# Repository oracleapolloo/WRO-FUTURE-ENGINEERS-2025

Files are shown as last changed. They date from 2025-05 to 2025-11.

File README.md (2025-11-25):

# WRO-FUTURE-ENGINEERS-2025 - TEAM APOLLO

<p align="center">
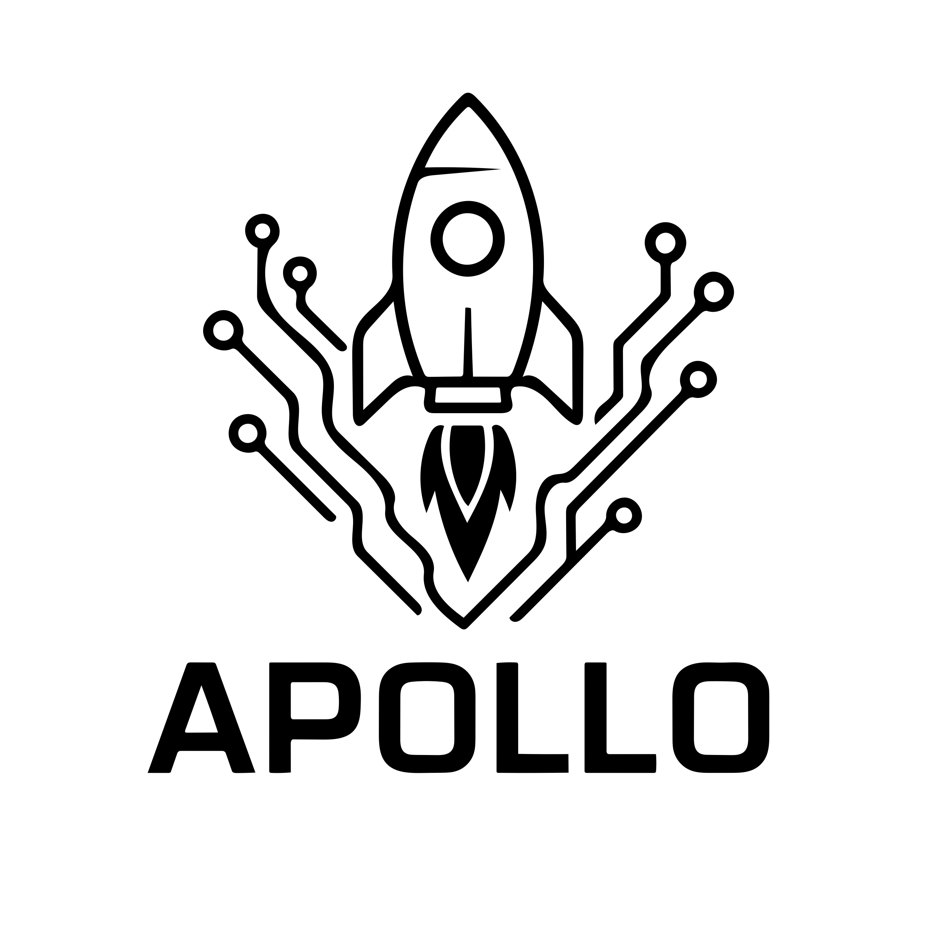
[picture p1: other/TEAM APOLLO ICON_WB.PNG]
  
  
  > An autonomous vehicle designed for the Future Engineers category of the WRO 2025 that uses advanced computer vision and IMU sensors to navigate complex environments and avoid obstacles intelligently.

---
  
##  Content Structure
* `t-photos` – Contains an official team photo and several funny group pics for the vibes 😄.  
* `v-photos` – Includes 6 vehicle images: top, bottom, front, back, left, and right.  
* `video` – Holds `video.md` with a link to the driving demonstration.  
* `schemes` – Contains a PDF file showing the full documentation, wiring, and electromechanical schematics of the robot setup.
* `src` – Full source code for all control components used in the competition.  
* `models` – Contains all STL files required for 3D printing the custom components used in the robot. 
* `other` – Contains all other supporting files, including resources used for the creation of this `README.md` and overall documentation.
* `obstacle challenge & open challenge` – Includes the complete codebase for both challenges.

---

##  Table of Contents

- [Overview](#overview)  
- [Team Introduction & Team Information](#team-introduction--team-information)  
- [Project Description](#project-description)  
- [Hardware Used](#hardware-used)  
- [Software & Libraries](#software--libraries)  
- [Competition Challenges](#competition-challenges)  
- [Spoilers](#spoilers)
  
---

##  Overview
This self-driving vehicle prototype, developed for the WRO Future Engineers 2025 competition, is a fully autonomous system combining real-time decision-making with a compact and modular hardware layout. It features a Limelight 3A for advanced object detection and color-based vision tracking, a REV Robotics 9-Axis IMU for precise orientation sensing and drift correction, and three REV Robotics 2m Distance Sensors for obstacle detection, wall following, and collision prevention. The robot's behavior is governed by a combination of PID control, filtered sensor data, and logic-based navigation, allowing it to maintain center alignment and adapt smoothly to changing track environments. Its structure includes prefabricated parts alongside custom 3D-printed mounts, optimized for precise sensor placement and clean wiring. Power is delivered via an 11.1V lithium-ion battery pack using three 18650 cells. The entire system is programmed using Python on Raspberry Pi 5, with modules communicating through PWM, UART, and I²C protocols to coordinate steering, sensors, and motor control. Altogether, this vehicle presents a robust and competition-ready platform that brings together mechanical design, embedded control systems, and smart autonomous behavior.

---

##  Team Introduction & Team Information
<table>
  <tr>
    <td align="center" width="33%">
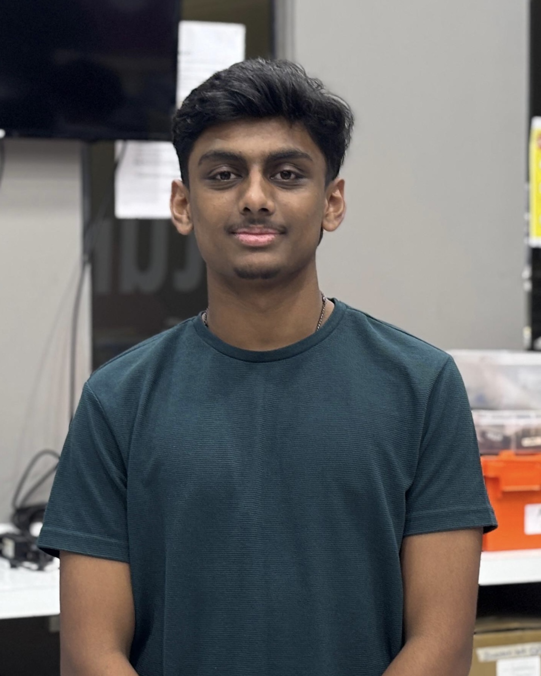
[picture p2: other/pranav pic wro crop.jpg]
      <br>
      <strong>PRANAV NAKKEERAN</strong><br>
      <em>Chief Strategist</em><br>
      <sub>Planning, Analysis, Iteration, Strategy Making</sub>
    </td>
    <td align="center" width="33%">
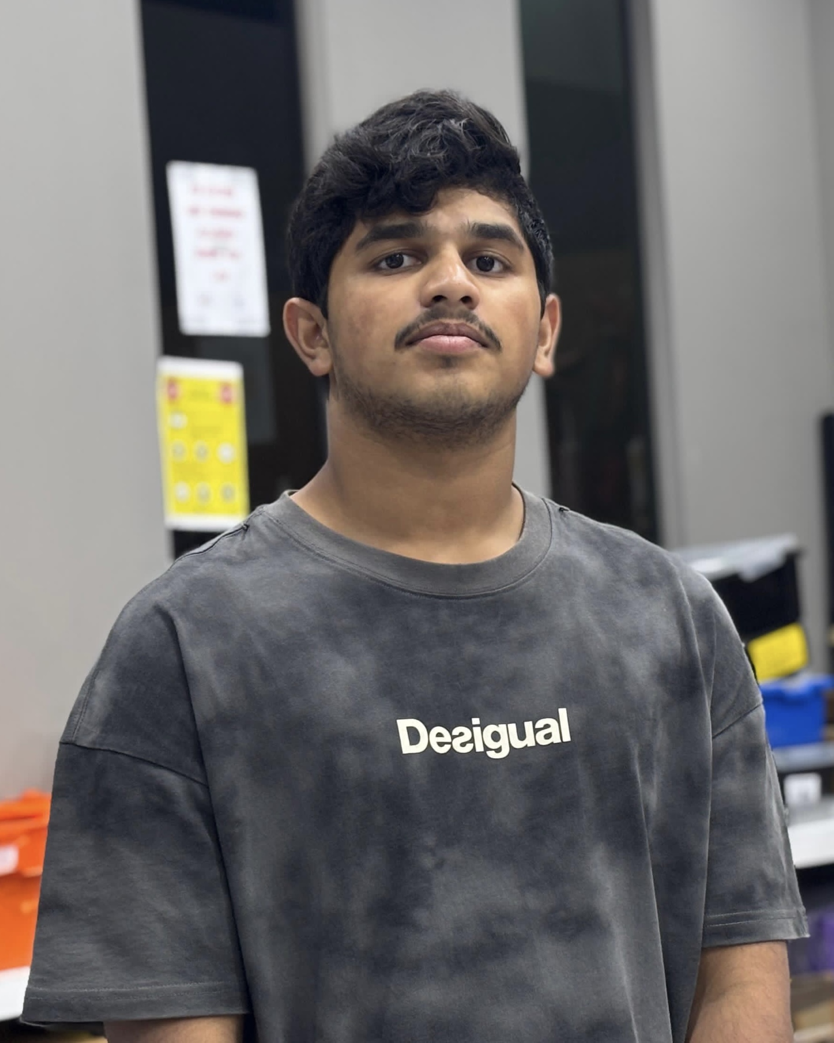
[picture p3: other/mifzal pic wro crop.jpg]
      <br>
      <strong>MOHAMED MIFZAL MAHAROOF</strong><br>
      <em>Hardware Engineer</em><br>
      <sub>Wiring, Circuit Design, Power Management</sub>
    </td>
    <td align="center" width="33%">
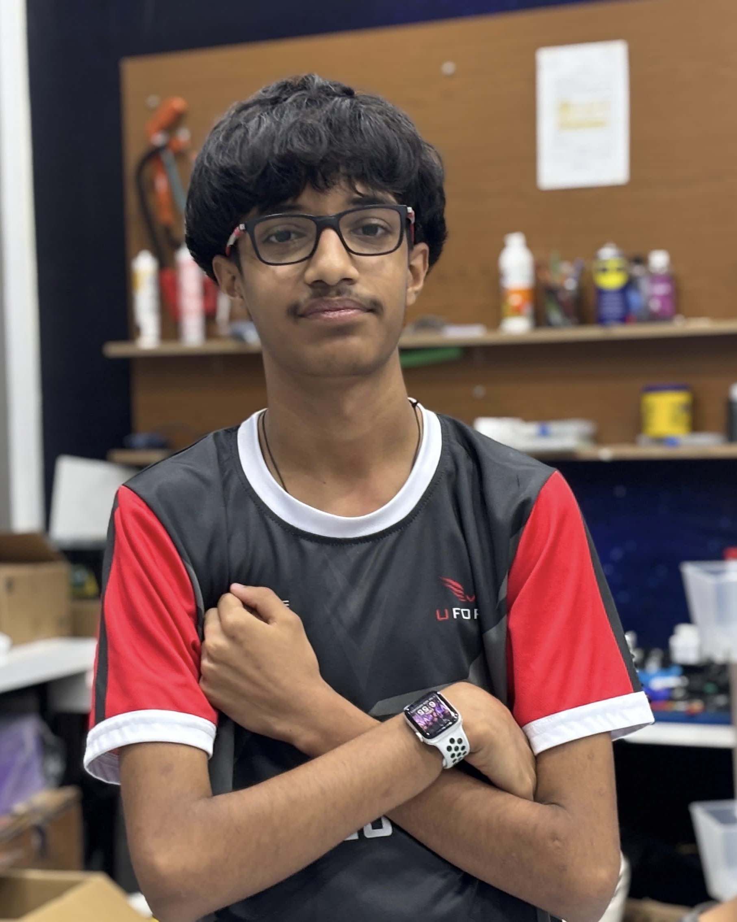
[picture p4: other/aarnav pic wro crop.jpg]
      <br>
      <strong>AARNAV BHARGAVA</strong><br>
      <em>Lead Programmer</em><br>
      <sub>Sensor Integration, Logic, Obstacle Avoidance</sub>
    </td>
  </tr>
</table>

---

##  Project Description

###  Problem Statement
How can a robot dynamically avoid both visible and invisible obstacles in real-time using multi-sensor fusion and advanced vision processing?

###  Goals
- Integrate AI vision with neural network processing for object detection.
- Use 9-axis IMU data to stabilize motion and track orientation with high precision.
- Implement ultrasonic-based distance awareness with improved accuracy.
- Ensure smooth motor control using high-current BTS7960 driver.
- Leverage Raspberry Pi 5's computational power for complex autonomous behaviors.

---

## � Hardware Used

### REV Robotics 2m Distance Sensors (3x)
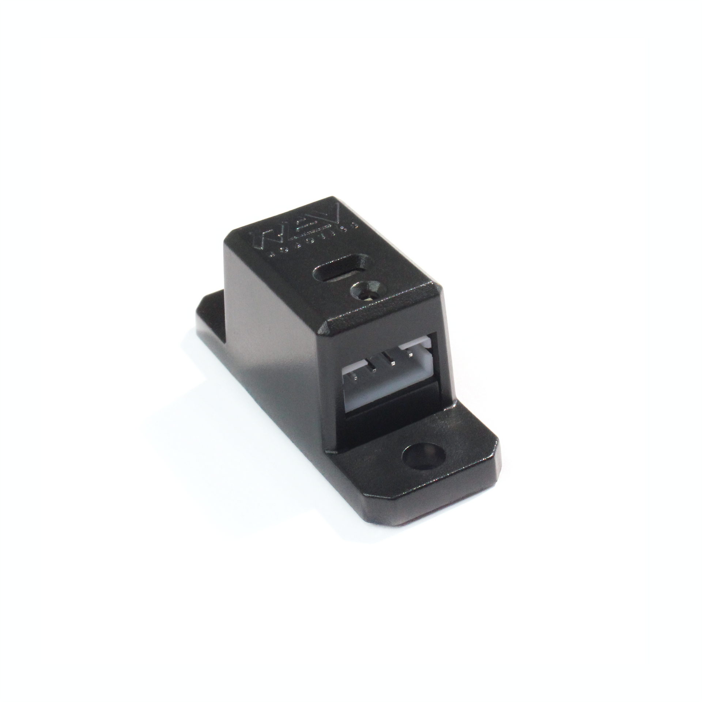
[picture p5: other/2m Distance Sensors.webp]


We selected the REV Robotics 2m Distance Sensor because it is:  
> - **Highly accurate** with ±1cm precision  
> - **Extended range** up to 2 meters for better obstacle detection  
> - **Easy to interface** with Raspberry Pi via I²C  
> - **Industrial-grade reliability** for consistent performance  
> - **Fast sampling rate** for real-time decision making

The REV Robotics 2m Distance Sensor uses Time-of-Flight (ToF) technology to measure distances with exceptional accuracy. Unlike traditional ultrasonic sensors, these ToF sensors emit infrared light pulses and calculate distance based on the time taken for light to reflect back, resulting in more precise and reliable measurements even in challenging lighting conditions.

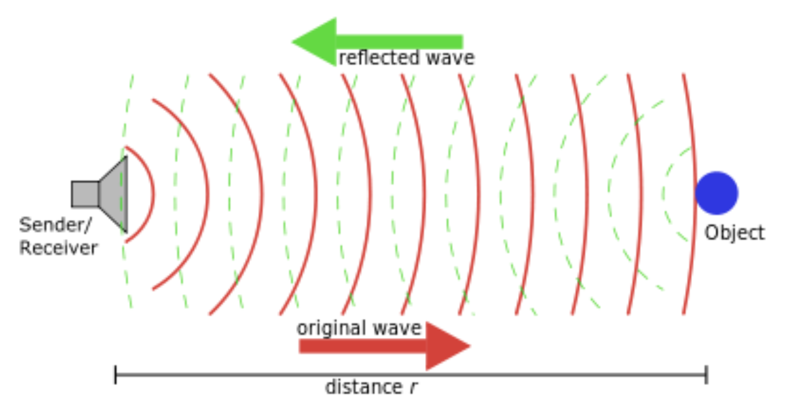
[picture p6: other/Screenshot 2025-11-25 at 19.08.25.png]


In our robot, we used **three REV Robotics Distance Sensors** — positioned at the front, left, and right. The front sensor provides **advanced collision avoidance**, detecting obstacles up to 2 meters away and allowing the robot to plan turns earlier. The side sensors handle **precision wall tracking and edge navigation**, maintaining optimal distance from boundaries while enabling intelligent turning decisions with millimeter-level accuracy.

In software, we utilize the sensors' built-in filtering capabilities and I²C communication protocol for rapid data acquisition. The extended range allows the robot to detect approaching obstacles sooner, giving more time for smooth trajectory adjustments. When the front sensor detects an obstacle, the system analyzes both side distances with high precision to determine the optimal turning direction, enhancing both safety and navigation efficiency.

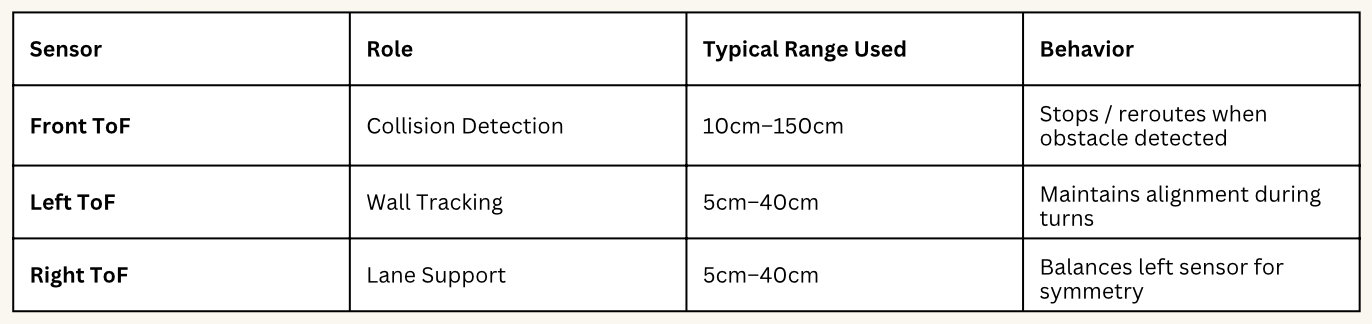
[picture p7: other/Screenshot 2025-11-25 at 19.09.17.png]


<br>

###  Axon MICRO+ Servo Motor
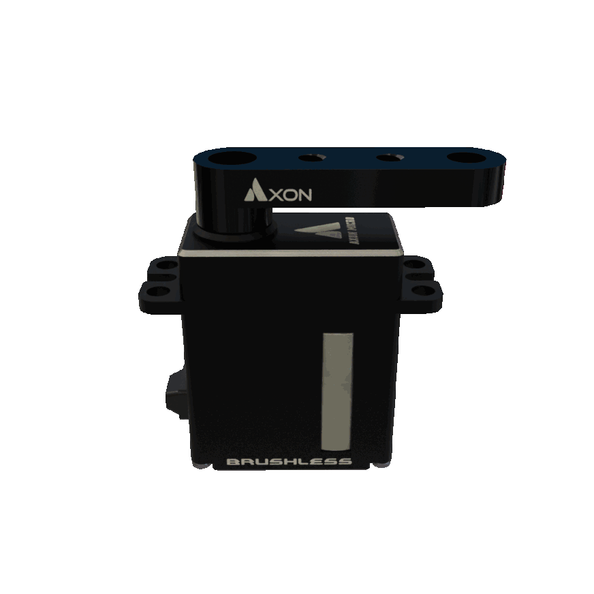
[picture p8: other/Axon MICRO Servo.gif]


Why we chose Axon MICRO+:
>- **270° rotation range** for enhanced steering flexibility
>- **Coreless motor design** for ultra-fast response
>- **Titanium gear construction** for maximum durability
>- **Programmable endpoints** for precise calibration
>- **High torque-to-weight ratio** (4.8kg-cm at 7.4V)
>- **Digital servo protocol** with position feedback

The Axon MICRO+ is a high-performance, programmable digital servo motor featuring coreless motor technology and titanium gears. This advanced servo provides 270° of rotation with exceptional precision and speed, making it ideal for responsive steering control in competitive robotics.

In our robot, we deployed the Axon MICRO+ as the primary steering actuator, enabling real-time directional adjustments with sub-degree accuracy. Its coreless motor eliminates cogging, resulting in silky-smooth motion and instantaneous response to control signals from the Raspberry Pi 5.

The servo is mechanically linked to the front wheels through an optimized Ackermann steering geometry with precision-cut gears. This configuration ensures both wheels turn synchronously at calculated angles, providing accurate steering even during high-speed maneuvers and tight corner navigation.

We selected this servo for its programmable features, allowing us to fine-tune endpoints, speed, and acceleration profiles through software. The titanium gears withstand the stress of repeated rapid movements, essential for completing multiple autonomous laps without mechanical degradation. The digital feedback capability enables closed-loop control, where the Raspberry Pi can verify actual servo position against commanded position, improving overall system reliability.

This motor ensures rapid, consistent, and precise directional control, dramatically improving the robot's agility and responsiveness in both obstacle-rich environments and open track sections while maintaining competitive speed.
<br>

###  AndyMark NeveRest Motor
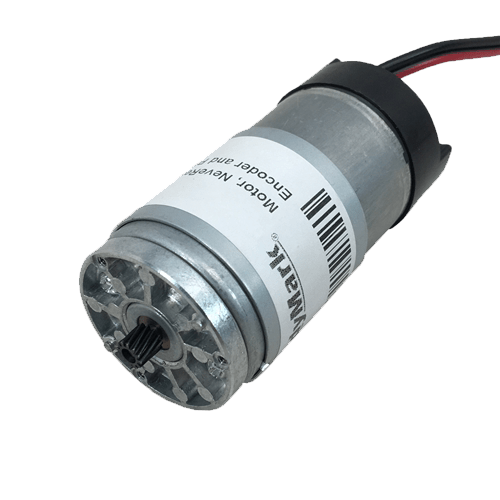
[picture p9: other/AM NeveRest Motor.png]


Why we chose the AndyMark NeveRest:
>- **High torque output** with multiple gear ratios available
>- **Integrated quadrature encoder** for precise position feedback
>- **Robust planetary gearbox** for reliable power transmission
>- **Wide voltage range** (6-12V) for flexible power management
>- **Efficient heat dissipation** for sustained performance
>- **Competition-proven reliability** in FTC/FRC events

The AndyMark NeveRest is a high-performance DC motor featuring a precision planetary gearbox and integrated Hall-effect encoder. This motor delivers exceptional torque while maintaining compact dimensions, making it perfect for driving our robot's differential drivetrain system.

We selected the NeveRest motor with a 20:1 gear ratio, providing an optimal balance between speed and torque for our application. The motor drives the robot's rear wheels through a custom differential assembly, enabling smooth acceleration, controlled speed variation, and reliable linear movement across diverse track surfaces.

The integrated quadrature encoder outputs 1120 counts per revolution, allowing the Raspberry Pi 5 to implement sophisticated closed-loop control algorithms. This encoder feedback enables precise speed regulation, accurate distance measurement, and coordinated motion control essential for executing complex autonomous navigation strategies.

We interface the NeveRest motor with the Raspberry Pi 5 through the BTS7960 high-current motor driver, which handles the motor's power requirements while the Raspberry Pi manages PWM speed control and direction signals. The system continuously monitors encoder feedback to maintain target speeds and adjust for load variations in real-time.

The motor's planetary gearbox provides smooth, reliable power transmission with minimal backlash, crucial for precise movement control during PID-based navigation and tight cornering maneuvers. Its robust construction withstands the repeated start-stop cycles and varying load conditions encountered during autonomous operation.

The combination of high torque, precision feedback, and durability made the NeveRest motor the ideal choice for driving our competition robot through challenging courses while maintaining consistent performance across multiple autonomous runs.
<br>

###  BTS7960 High-Current Motor Driver
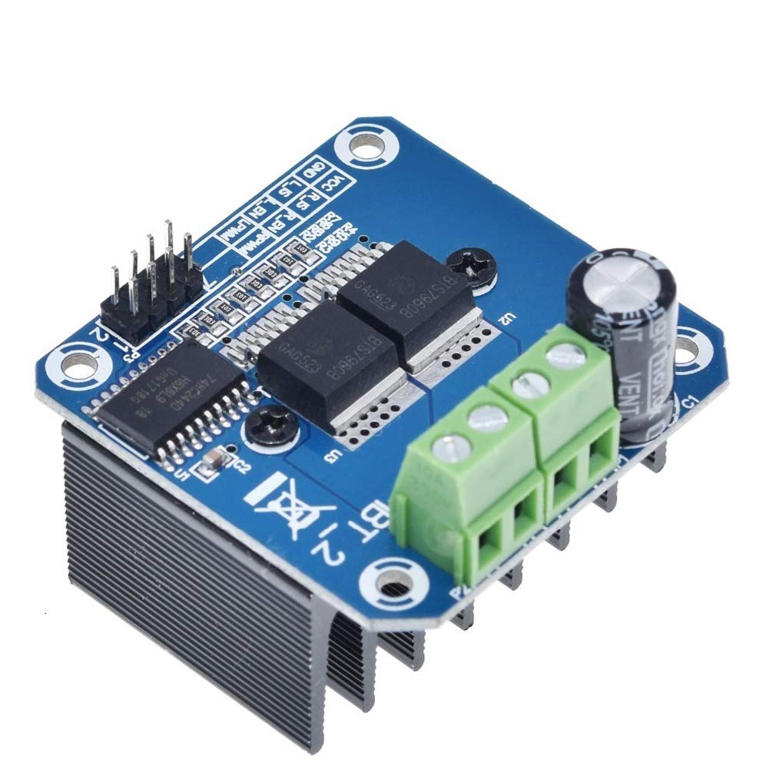
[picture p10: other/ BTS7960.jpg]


Why we chose BTS7960:
>- **High current capacity** up to 43A continuous
>- **Full H-bridge** for bidirectional control
>- **PWM frequency** up to 25kHz for smooth operation
>- **Over-current and thermal protection** built-in
>- **Low voltage drop** for efficient power delivery
>- **Isolated signal inputs** for noise immunity

The BTS7960 is a professional-grade, high-current H-bridge motor driver module capable of handling the demanding power requirements of high-performance DC motors. It features two Infineon BTS7960 chips configured as a full H-bridge, providing robust bidirectional motor control with exceptional current handling capabilities.

In our design, the BTS7960 serves as the primary interface between the Raspberry Pi 5 and the AndyMark NeveRest motor. It receives PWM signals from the Raspberry Pi for speed control and digital logic signals for direction management. This configuration allows us to implement sophisticated motor control algorithms including acceleration profiling, dynamic speed adjustment, and regenerative braking simulation.

The driver's high current capacity (43A continuous, 100A peak) provides substantial headroom for our motor's demands, even during rapid acceleration or high-load situations. This prevents voltage sag and ensures consistent motor performance throughout competition runs. The module's built-in protection features guard against over-current conditions, short circuits, and thermal overload, protecting both the driver and the expensive NeveRest motor.

Unlike lower-capacity drivers, the BTS7960 maintains efficiency at high currents with minimal heat generation thanks to its low RDS(on) and integrated heat sinking. The isolated signal inputs protect the Raspberry Pi from electrical noise generated by motor switching, ensuring stable I²C and encoder signal integrity.

The driver's high PWM frequency capability (up to 25kHz) eliminates audible motor whine and produces smoother torque delivery, particularly beneficial for precision speed control during wall-following and PID correction maneuvers. This results in more stable sensor readings and improved overall system performance.

The BTS7960's combination of high current handling, robust protection features, and clean signal operation made it the essential choice for reliable, high-performance motor control in our competition-grade autonomous vehicle.
<br>

###  Raspberry Pi 5 8GB - Main Controller
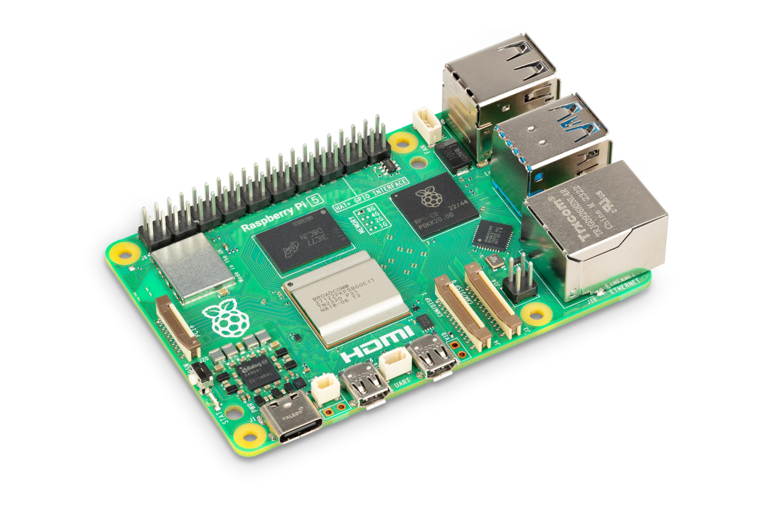
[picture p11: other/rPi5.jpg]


Key reasons we chose the Raspberry Pi 5 8GB:
>- **Quad-core ARM Cortex-A76 CPU** running at 2.4GHz
>- **8GB LPDDR4X RAM** for complex vision processing
>- **Dual 4K display outputs** for development debugging
>- **PCIe 2.0 interface** for high-speed peripherals
>- **Native USB 3.0** for fast data transfer
>- **Real-time capabilities** with improved GPIO performance
>- **Python and C++ support** with extensive libraries
>- **Active community** and professional documentation

The Raspberry Pi 5 represents a significant leap in single-board computer performance, serving as the central processing unit for our autonomous robot. Featuring a quad-core 64-bit ARM Cortex-A76 processor running at 2.4GHz and 8GB of high-speed LPDDR4X memory, it provides the computational power necessary for running complex vision algorithms, sensor fusion, and real-time control systems simultaneously.

In our system architecture, the Raspberry Pi 5 functions as the robot's brain, processing inputs from the Limelight 3A vision system, REV Robotics 9-Axis IMU, and three distance sensors while executing sophisticated navigation algorithms and generating precise control outputs to the BTS7960 motor driver and Axon MICRO+ servo.

We selected the 8GB model specifically to support simultaneous operation of the vision processing pipeline, neural network inference (if required), sensor data filtering, PID controllers, and logging systems without memory constraints. The increased RAM allows us to maintain larger data buffers and implement more sophisticated prediction algorithms for smoother robot behavior.

The Raspberry Pi 5's improved GPIO performance with dedicated RP1 I/O controller enables more reliable PWM generation and faster I²C communication with sensors. This results in higher servo update rates and reduced latency in motor control responses, critical for maintaining stability during high-speed operation.

Programming flexibility is a key advantage - we develop in Python for rapid prototyping and algorithm testing, with the option to optimize critical sections in C++ when needed. The extensive software ecosystem provides libraries for vision processing (OpenCV), numerical computation (NumPy), and hardware interfaces (pigpio, gpiozero), accelerating development and enabling sophisticated features.

The built-in dual-band WiFi enables wireless code deployment, real-time telemetry monitoring, and remote debugging during testing sessions, significantly streamlining our development workflow. The PCIe interface future-proofs our design, allowing for potential addition of AI accelerators or high-speed storage if needed.

Power management is handled efficiently, with the board drawing appropriate current for the computational load while remaining stable under the demanding conditions of autonomous navigation. The improved thermal design with official active cooling accessories ensures sustained performance even during extended competition runs.

The Raspberry Pi 5's combination of processing power, memory capacity, connectivity options, and development ecosystem made it the natural choice for controlling our advanced competition robot, enabling implementation of sophisticated autonomous behaviors that were previously impractical on lower-powered platforms.
<br>

###  REV Robotics 9-Axis IMU – Inertial Measurement Unit
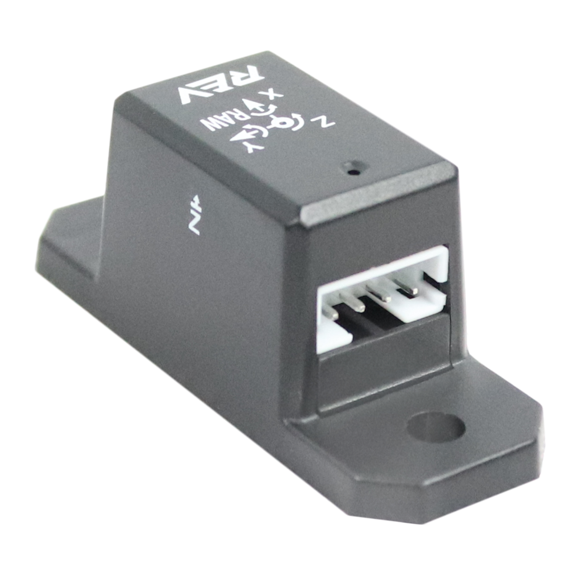
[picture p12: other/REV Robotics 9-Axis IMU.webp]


Why we chose the REV Robotics 9-Axis IMU:
>- **9-axis sensor fusion** (3-axis accelerometer, gyroscope, magnetometer)
>- **BNO055 smart sensor** with onboard processing
>- **Quaternion output** for gimbal-lock-free orientation
>- **Automatic calibration** with persistent storage
>- **I2C interface** compatible with Raspberry Pi
>- **Industrial temperature range** for reliability
>- **Pre-configured** for robotics applications

The REV Robotics 9-Axis IMU features the Bosch BNO055 intelligent sensor, which combines a 3-axis accelerometer, 3-axis gyroscope, and 3-axis magnetometer with an integrated ARM Cortex-M0 processor. This advanced IMU provides real-time orientation data through sophisticated sensor fusion algorithms executed entirely on-chip, offloading computational burden from the main processor.

In our robot, this IMU serves as the cornerstone of our navigation system, providing absolute orientation tracking with exceptional accuracy and stability. The sensor fusion algorithm combines data from all nine axes to output orientation in multiple formats: Euler angles, quaternions, and rotation vectors, giving us flexibility in implementing our control algorithms.

We primarily utilize the IMU's heading (yaw) data for maintaining straight-line tracking and executing precise turns. The quaternion output eliminates gimbal lock issues that plague simpler 6-axis IMUs, ensuring reliable orientation data even during complex maneuvers. The onboard sensor fusion provides filtered, drift-compensated heading values at 100Hz update rates, enabling smooth and responsive PID control.

The BNO055's automatic calibration system is particularly valuable - it continuously monitors sensor performance and adjusts calibration parameters, storing them in non-volatile memory. This means our robot maintains consistent orientation accuracy across power cycles and environmental variations without requiring manual recalibration.

Unlike basic IMUs like the MPU6050, the REV Robotics unit includes a magnetometer for absolute heading reference. This prevents the cumulative drift typical of gyroscope-only solutions, essential for accurate navigation over extended autonomous runs. The accelerometer complements the gyroscope by detecting dynamic motion changes and providing orientation reference during stationary periods.

Integration with the Raspberry Pi 5 is straightforward via I²C protocol, with REV providing well-documented Python libraries specifically designed for FIRST Tech Challenge and educational robotics. These libraries abstract low-level register manipulation while providing access to advanced features like interrupt-driven updates and custom axis remapping.

The IMU's robust construction and industrial-grade components ensure reliable operation despite the vibrations and occasional impacts inherent in competitive robotics. Its compact form factor and mounting hole pattern facilitate secure installation at the robot's center of gravity, minimizing rotational coupling effects that could introduce noise into orientation measurements.

The combination of sophisticated sensor fusion, absolute heading reference, automatic calibration, and reliable performance made the REV Robotics 9-Axis IMU the definitive choice for providing our robot with accurate, stable orientation data essential for precise autonomous navigation and smooth motion control.
<br>

###  Limelight 3A - Advanced Vision Sensor
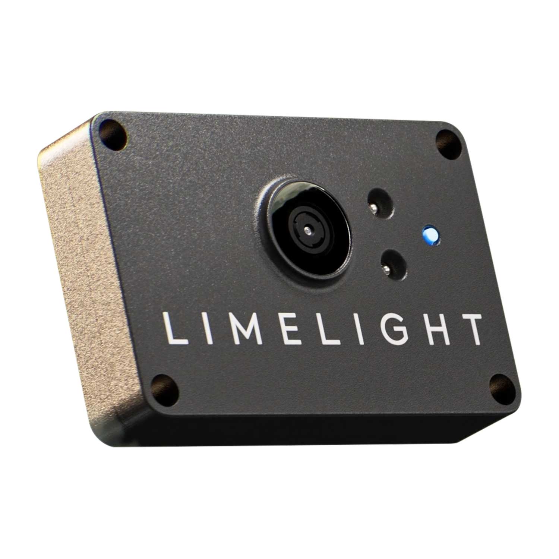
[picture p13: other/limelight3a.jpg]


Key reasons we chose Limelight 3A:  
> - **Neural network processing** with Google Coral TPU  
> - **High-resolution camera** (1920×1080 at 90fps)  
> - **AprilTag detection** with sub-pixel accuracy  
> - **Color-based object tracking** with HSV filtering  
> - **NetworkTables API** for seamless integration  
> - **Web-based configuration** for easy tuning  
> - **3D pose estimation** for spatial awareness  
> - **Snapshot and recording** capabilities for debugging

The Limelight 3A represents a significant advancement in vision processing for competitive robotics, featuring a high-resolution camera paired with a Google Coral Edge TPU for on-device neural network inference. This intelligent vision sensor performs sophisticated image processing entirely onboard, delivering position, size, and classification data over NetworkTables with minimal latency.

In our robot, the Limelight 3A serves as the primary visual perception system, enabling detection and tracking of colored markers, AprilTags, and custom-trained objects critical for autonomous navigation in competition environments. The integrated Edge TPU allows us to run custom TensorFlow Lite models for object detection without overwhelming the Raspberry Pi 5's main processor.

We configured multiple vision pipelines within the Limelight, each optimized for different tasks: color blob detection for tracking field markers, AprilTag detection for precision positioning, and neural network inference for identifying specific game elements. The sensor can switch between these pipelines programmatically, adapting to different phases of autonomous operation.

The high frame rate capability (90fps at 1080p, 120fps at 720p) provides smooth, responsive tracking even during rapid robot motion. This high temporal resolution enables our control algorithms to react quickly to changing visual conditions, improving trajectory accuracy and obstacle response times.

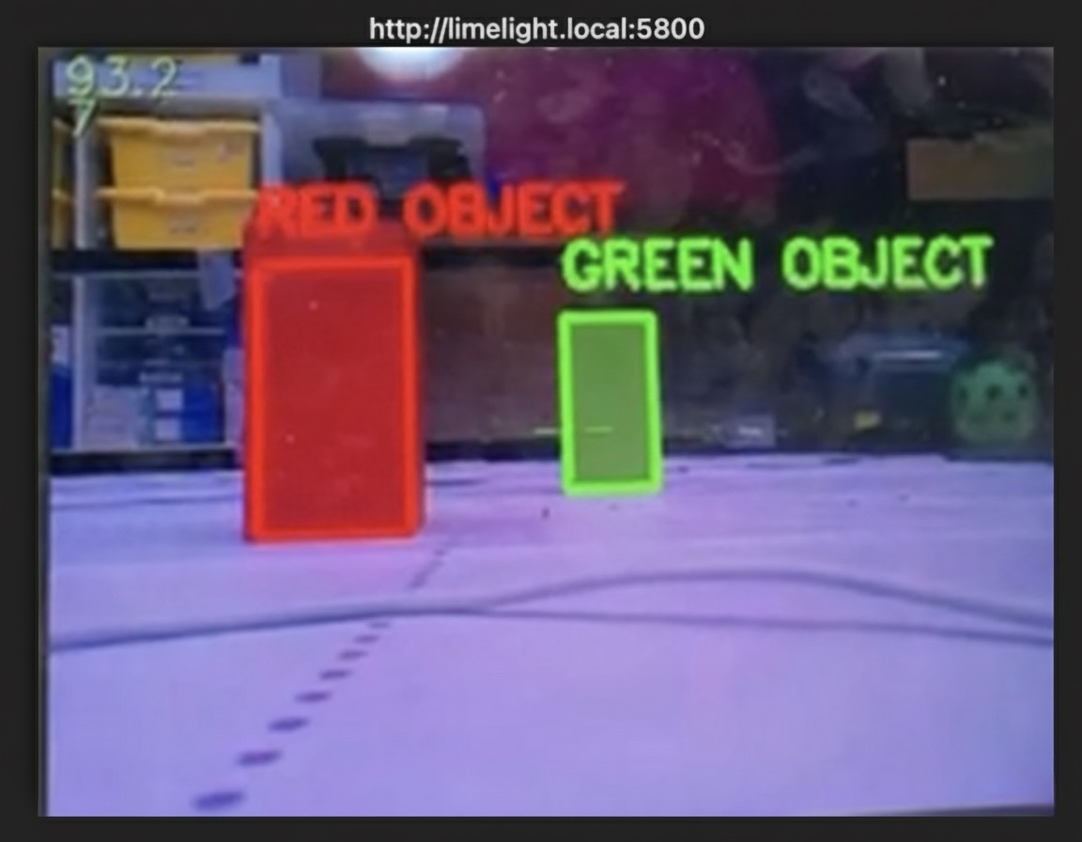
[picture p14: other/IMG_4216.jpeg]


Unlike simpler vision sensors, the Limelight 3A outputs comprehensive targeting data including: horizontal and vertical angles to target, bounding box dimensions, target area, skew, and corner coordinates. For AprilTags, it additionally provides 6DOF pose information (X, Y, Z position and roll, pitch, yaw orientation), enabling precise spatial reasoning and positioning.

The web-based configuration interface allows us to fine-tune vision pipelines in real-time during testing. We can adjust HSV thresholds, erosion/dilation parameters, contour filtering rules, and neural network confidence levels while observing the processed image stream, dramatically speeding up calibration for different lighting conditions.

NetworkTables integration provides a robust, low-latency communication channel to the Raspberry Pi 5. The Limelight publishes detection results at high frequency, and the Raspberry Pi can programmatically control camera settings, switch pipelines, and trigger snapshots for logging. This bidirectional communication enables adaptive vision processing based on robot state.

The Limelight's 3D positioning capabilities are particularly valuable for complex navigation scenarios. Using stereo AprilTag pairs or known-size objects, the sensor calculates precise distance and angle measurements, enabling accurate approach maneuvers and positioning tasks that would be impractical with simple 2D vision.

The robust construction, industrial-grade camera sensor, and professional-level processing power made the Limelight 3A an essential component for giving our robot sophisticated visual perception capabilities. It transforms raw visual information into actionable navigation data, enabling intelligent decision-making and precise autonomous operation in dynamic competition environments.
<br>

###  Power Supply (3x 18650 Battery Pack)
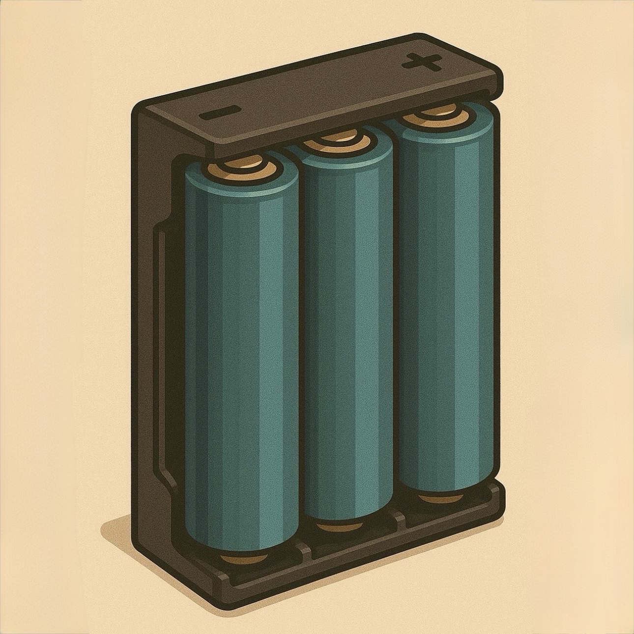
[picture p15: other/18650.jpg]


Why we chose this power system:  
> - **Compact & modular** battery solution  
> - **Optimal voltage** (11.1V nominal) for motor driver  
> - **High discharge rate** (20A continuous capability)  
> - **Stable voltage curve** throughout discharge cycle  
> - **Rechargeable & easily replaceable** cells  
> - **Built-in protection circuitry** for safety  
> - **Lightweight** compared to equivalent lead-acid  
> - **Consistent current delivery** under load

The robot is powered by three **Samsung 30Q 18650 lithium-ion batteries** connected in series through a protected battery holder, providing approximately **11.1V nominal** (12.6V fully charged, 9V minimum) total output. This 3S configuration offers an excellent energy density of 3000mAh, delivering sustained power for extended autonomous runs while maintaining manageable weight.

Our power distribution architecture carefully manages voltage requirements for different subsystems. The **BTS7960 motor driver** and **AndyMark NeveRest motor** operate directly from the 11.1V battery supply, benefiting from maximum available voltage for optimal torque and speed. The **Raspberry Pi 5** requires 5V/5A, supplied through a high-efficiency UBEC (Universal Battery Elimination Circuit) regulator that maintains stable voltage even during motor current spikes.

The **Axon MICRO+ servo** is powered through a separate 6V/3A UBEC to provide clean power isolated from motor noise. The **REV Robotics IMU**, **distance sensors**, and **Limelight 3A** draw power from the Raspberry Pi 5's USB and GPIO power rails, which are rated for sufficient current capacity while providing proper voltage regulation.

All subsystems share a **common ground plane** connected through a central distribution board, ensuring consistent voltage references across digital communication buses (I²C, UART) and preventing ground loops that could introduce noise into sensor readings. Power cables are properly sized - 14AWG silicone wire for motor circuits, 20AWG for servo, and 22AWG for logic-level connections.

The battery pack includes integrated protection circuitry monitoring cell voltages and preventing over-discharge below 9V (3V per cell), over-charge above 12.6V (4.2V per cell), short-circuit conditions, and excessive current draw. This protection extends battery life and prevents dangerous operating conditions.

During competition runs, the battery typically operates in the 11.1V-10.5V range, providing consistent performance. At 10.5V, we implement a low-battery warning through the Raspberry Pi, prompting a battery change to maintain optimal motor performance. The 3000mAh capacity provides approximately 15-20 minutes of active competition time depending on motor usage intensity.

We selected Samsung 30Q cells specifically for their high discharge rating (15A continuous, 20A peak per cell) and stable voltage curve under load. Unlike lower-quality cells that exhibit significant voltage sag during current spikes, these cells maintain relatively flat voltage output, ensuring consistent motor speeds and servo response throughout each run.

The modular nature of 18650 cells allows us to carry spare batteries and quickly swap the entire pack between runs. We maintain multiple battery sets in rotation, charging depleted packs while using fresh ones, ensuring we're always ready for the next competition round.

This power system architecture provides reliable, stable, and sufficient electrical power to all robot subsystems while maintaining safety, weight efficiency, and operational flexibility essential for competitive autonomous robotics.
<br>

###  Custom 3D Printed Components
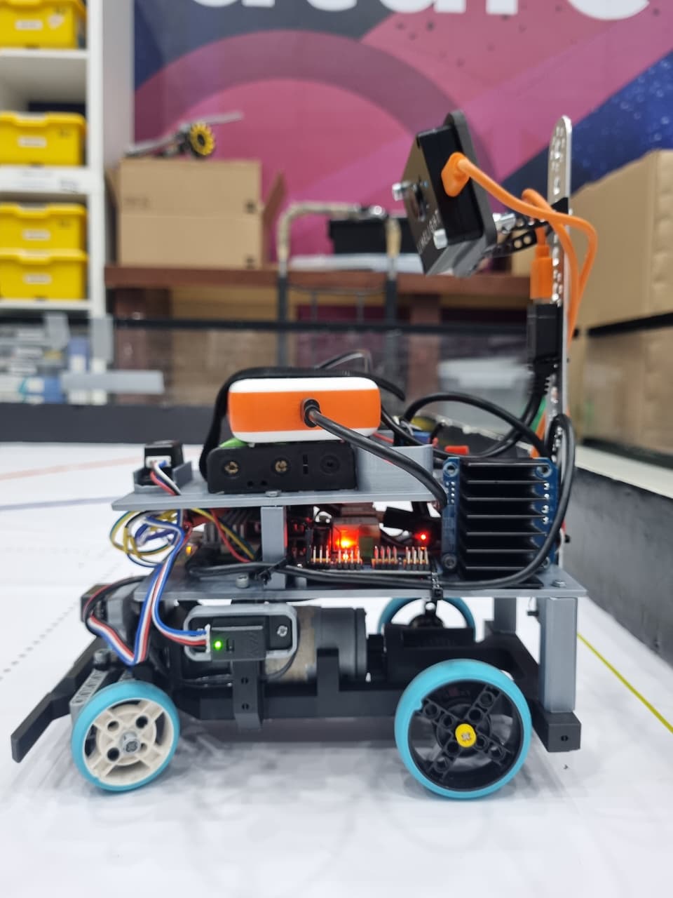
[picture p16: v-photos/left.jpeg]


Why we 3D printed select components:  
> - **Precise sensor mounting** with designed alignment features  
> - **Optimized center of gravity** placement for IMU accuracy  
> - **Modular design** enabling rapid repairs or iterations  
> - **Custom cable management** integrated into structure  
> - **Vibration dampening** through strategic material choice  
> - **Lightweight** compared to machined alternatives  
> - **Complex geometries** impossible with traditional fabrication  
> - **Perfect fit** for commercial off-the-shelf components

While our robot's main chassis utilizes a combination of aluminum extrusion, laser-cut acrylic panels, and commercial mounting hardware, we designed and 3D printed specific components to optimize performance, improve integration, and solve unique mechanical challenges inherent to our design.

Critical 3D printed parts include the **REV Robotics IMU mounting bracket** positioned precisely at the robot's geometric center and rotational axis, the **Limelight 3A camera housing** with integrated cooling airflow channels, **REV distance sensor mounts** providing exact angular alignment for optimal coverage, and a **Raspberry Pi 5 mounting tray** with standoffs designed for both mechanical support and thermal management.

The IMU mounting bracket represents perhaps the most important printed component. We designed it to position the sensor at the robot's center of mass with minimal distance from the pitch/roll/yaw axes. This strategic placement dramatically reduces the effect of linear accelerations on gyroscope readings and minimizes rotational noise during turns. The bracket incorporates rubber isolation standoffs to filter high-frequency vibrations from the drivetrain while maintaining rigid coupling for low-frequency motion - essential for accurate sensor fusion.

For the Limelight 3A, we created a custom housing that maintains the required camera angle while providing protection from impacts and organizing cable routing. The housing features built-in channels that guide cooling air past the Google Coral TPU, preventing thermal throttling during extended vision processing. Quick-release latches allow rapid camera adjustment or replacement without tools.

Distance sensor mounts were precision-designed to aim each REV sensor at its optimal coverage zone - front sensor parallel to the ground for obstacle detection, side sensors angled slightly downward to minimize false readings from overhead structures while maintaining wall-following accuracy. Each mount includes adjustment slots for fine-tuning sensor aim during calibration.

The Raspberry Pi 5 mounting solution addresses both mechanical and thermal requirements. The tray positions the board for optimal wire routing to peripherals while elevating it above other components to prevent electromagnetic interference. Integrated standoffs maintain precise spacing for the official active cooler, and strategic cutouts facilitate airflow circulation. The design also incorporates cable management clips that organize power and data connections.

Additional printed components include: servo horn adapters matching the Axon MICRO+ spline to our steering linkage, motor shaft couplers connecting the NeveRest output to the differential input with precise concentricity, battery retention clips that secure the 18650 pack while allowing quick replacement, and cable routing guides that maintain organized wiring throughout the chassis.

We designed all components in Fusion 360, utilizing parametric modeling to ensure precise dimensions and fit. Parts are printed using PETG filament on an FDM printer with 0.2mm layer height and 30% gyroid infill - this combination provides excellent strength-to-weight ratio, dimensional stability across temperature ranges, and adequate flexibility to absorb minor impacts without fracturing.

Material selection varied by component: PETG for structural parts requiring strength and dimensional stability, TPU for vibration-isolating IMU mounts, and ABS for the Limelight housing requiring higher temperature resistance near the active components.

The layer orientation for each part was carefully considered during slicing - sensor mounts are printed with layers oriented to maximize strength against mounting stresses, while the Pi tray uses layers parallel to the board surface for optimal support distribution.

Post-processing included careful deburring of mounting holes, acetone vapor smoothing for ABS parts requiring precise fits, and insertion of heat-set threaded inserts in high-stress mounting points. These inserts provide robust, repeatable fastening that won't strip like printed threads.

This hybrid approach - combining commercial structural components with custom 3D printed integration parts - provided the flexibility to rapidly prototype, test, and refine our mechanical design while maintaining structural integrity and professional build quality. The ability to iterate sensor mounts and adjust mounting positions within hours rather than days proved invaluable during the optimization phase of development.

The modular nature of our printed components means we can quickly replace damaged parts or upgrade specific subsystems without rebuilding the entire chassis. We maintain a library of spare parts and alternative designs, enabling us to adapt to rule changes or implement improvements between competition rounds.
<br>

---

##  Software & Libraries

### Development Environment:
- **Python 3.11** - Primary programming language
- **Raspberry Pi OS (64-bit)** - Operating system
- **Visual Studio Code** - Code editor with remote SSH
- **Git** - Version control and collaboration

### Key Python Libraries:
- **RPi.GPIO** - GPIO control and PWM generation
- **smbus2** - I²C communication with IMU and sensors
- **pynetworktables** - Communication with Limelight 3A
- **opencv-python** - Additional image processing if needed
- **numpy** - Numerical computations and array operations
- **pigpio** - High-precision PWM for servo control

### Hardware Interface Libraries:
- **REV Robotics Python Library** - IMU and sensor drivers
- **gpiozero** - Simplified GPIO control
- **adafruit-circuitpython-motor** - Motor control abstractions

---

## 🔧 Core Software Functions

### getFilteredDistance():
#### Reliable Sensor Reading with Advanced Filtering
```python
import numpy as np
from statistics import median

def getFilteredDistance(sensor):
    """
    Reads distance from REV 2m sensor with median filtering
    and outlier rejection for stable measurements.
    """
    samples = 5
    readings = []
    
    for _ in range(samples):
        try:
            distance = sensor.read_distance()
            if 2 <= distance <= 200:  # Valid range in cm
                readings.append(distance)
        except Exception as e:
            print(f"Sensor read error: {e}")
        time.sleep(0.01)
    
    if len(readings) < 3:
        return MAX_DISTANCE  # No valid readings
    
    # Use median to reject outliers
    filtered_distance = median(readings)
    
    # Additional smoothing with exponential moving average
    global distance_ema
    alpha = 0.3  # Smoothing factor
    distance_ema = alpha * filtered_distance + (1 - alpha) * distance_ema
    
    return distance_ema
```
> **Purpose**: Provides noise-resistant distance measurements from REV sensors  
> **Enhancements**: Uses median filtering (better than mean for outlier rejection) + exponential moving average for smooth transitions  
> **Impact**: Eliminates spurious readings that could cause erratic behavior, enables stable wall-following  
> **Why filter**: ToF sensors can occasionally return erroneous values; multiple samples with statistical filtering ensure reliability

### performTurn():
#### Precision Turns Using 9-Axis IMU
```python
def performTurn(clockwise, target_angle_change=88):
    """
    Executes precise turn using REV 9-Axis IMU quaternion data
    with PID control for accurate heading changes.
    """
    imu.update()
    start_heading = imu.get_heading()  # Get current yaw angle
    
    # Calculate target heading (handle 0-360 wraparound)
    if clockwise:
        target_heading = (start_heading - target_angle_change) % 360
    else:
        target_heading = (start_heading + target_angle_change) % 360
    
    # Set steering to maximum for quick turn initiation
    servo.set_angle(SERVO_MAX_RIGHT if clockwise else SERVO_MAX_LEFT)
    motor.set_speed(TURN_SPEED)
    
    # PID controller for smooth turn completion
    kp = 2.0
    kd = 0.5
    last_error = 0
    
    while True:
        imu.update()
        current_heading = imu.get_heading()
        
        # Calculate shortest angular distance to target
        error = calculate_angular_error(current_heading, target_heading)
        
        # Exit condition: within 2 degrees of target
        if abs(error) < 2:
            break
        
        # PID correction as we approach target
        derivative = error - last_error
        correction = kp * error + kd * derivative
        
        # Gradually reduce steering angle as we approach target
        servo_angle = SERVO_CENTER + int(correction)
        servo_angle = constrain(servo_angle, SERVO_MAX_LEFT, SERVO_MAX_RIGHT)
        servo.set_angle(servo_angle)
        
        last_error = error
        time.sleep(0.02)  # 50Hz control loop
    
    # Stop and center steering
    motor.set_speed(0)
    servo.set_angle(SERVO_CENTER)
    
    # Update global target for straight-line tracking
    global target_heading
    target_heading = target_heading

def calculate_angular_error(current, target):
    """Calculate shortest angular distance handling 0-360 wraparound"""
    error = target - current
    if error > 180:
        error -= 360
    elif error < -180:
        error += 360
    return error
```
> **Purpose**: Executes accurate 90° turns using IMU feedback  
> **Precision Control**: PID loop ensures consistent turn angles regardless of battery voltage or surface friction  
> **Smart Navigation**: Handles 0-360° wraparound correctly, calculates shortest rotation path  
> **Competition Critical**: Accurate turns are essential for lap counting and edge detection

### Main Control Logic:
#### Advanced Multi-Sensor Navigation with Sensor Fusion
```python
def main_control_loop():
    """
    Main autonomous navigation loop combining vision, IMU, and distance sensors
    with multi-factor PID control for smooth, adaptive driving.
    """
    global target_heading, direction_set, is_clockwise, edge_count
    
    # Control gains (tuned through testing)
    KP_GYRO = 1.5      # Gyroscope heading correction
    KP_WALL = 0.8      # Inner wall distance correction
    KP_OUTER = 1.2     # Outer wall avoidance
    KP_VISION = 2.0    # Limelight target tracking
    
    while is_running:
        # Update all sensors
        imu.update()
        current_heading = imu.get_heading()
        
        # Get filtered distance readings
        front_dist = getFilteredDistance(sensor_front)
        left_dist = getFilteredDistance(sensor_left)
        right_dist = getFilteredDistance(sensor_right)
        
        # Get vision data from Limelight
        vision_target = limelight.get_target()
        
        # Calculate base heading error
        heading_error = calculate_angular_error(current_heading, target_heading)
        
        # Initialize steering correction
        steering_correction = 0
        
        # Multi-factor correction based on current state
        if direction_set and not is_waiting:
            # Determine which wall to follow
            inner_dist = left_dist if is_clockwise else right_dist
            outer_dist = right_dist if is_clockwise else left_dist
            
            # Inner wall following correction
            wall_error = TARGET_WALL_DISTANCE - inner_dist
            steering_correction += KP_WALL * wall_error
            
            # Outer wall avoidance (if too close)
            if outer_dist < OUTER_WALL_THRESHOLD:
                outer_error = OUTER_WALL_THRESHOLD - outer_dist
                steering_correction += KP_OUTER * outer_error * (-1 if is_clockwise else 1)
            
            # Vision-based correction (if target detected)
            if vision_target['valid']:
                # Target X offset from center (-1 to 1)
                vision_error = vision_target['tx'] / 27.0  # Normalize
                steering_correction += KP_VISION * vision_error
        
        # Always apply gyro correction for drift compensation
        steering_correction += KP_GYRO * heading_error
        
        # Calculate final servo angle
        servo_angle = SERVO_CENTER + int(steering_correction)
        servo_angle = constrain(servo_angle, SERVO_MAX_LEFT, SERVO_MAX_RIGHT)
        
        # Apply steering
        servo.set_angle(servo_angle)
        
        # Motor speed control based on steering angle (slow in sharp turns)
        if abs(steering_correction) > 20:
            motor_speed = SLOW_SPEED
        else:
            motor_speed = NORMAL_SPEED
        
        motor.set_speed(motor_speed)
        
        # Check for turn conditions
        check_turn_conditions(left_dist, right_dist, front_dist)
        
        time.sleep(0.02)  # 50Hz main loop

def check_turn_conditions(left_dist, right_dist, front_dist):
    """Detect when to initiate turns based on distance sensor readings"""
    global direction_set, is_clockwise, edge_count, is_waiting
    
    # Obstacle ahead - emergency response
    if front_dist < OBSTACLE_THRESHOLD:
        # Determine safer direction
        if left_dist > right_dist:
            performTurn(clockwise=False)
        else:
            performTurn(clockwise=True)
        return
    
    # Initial direction detection
    if not direction_set:
        if right_dist > SIDE_TURN_DISTANCE:
            is_clockwise = True
            direction_set = True
            edge_count += 1
            performTurn(is_clockwise)
            set_waiting_state()
        elif left_dist > SIDE_TURN_DISTANCE:
            is_clockwise = False
            direction_set = True
            edge_count += 1
            performTurn(is_clockwise)
            set_waiting_state()
    
    # Subsequent corner detection
    elif not is_waiting:
        outer_dist = right_dist if is_clockwise else left_dist
        
        if outer_dist > SIDE_TURN_DISTANCE:
            edge_count += 1
            
            # Check if we've completed required laps
            if edge_count >= TOTAL_EDGES:
                performTurn(is_clockwise)  # Final turn
                time.sleep(1.0)  # Drive forward briefly
                motor.set_speed(0)  # Stop
                global is_running
                is_running = False
                return
            
            performTurn(is_clockwise)
            set_waiting_state()

def set_waiting_state():
    """Prevent repeated turn detection after corner"""
    global is_waiting, wait_start_time
    is_waiting = True
    wait_start_time = time.time()
    
def update_waiting_state():
    """Check if enough time has passed to resume turn detection"""
    global is_waiting
    if is_waiting and (time.time() - wait_start_time) > WAIT_DURATION:
        is_waiting = False
```
> **Multifactor Decision System**: Blends four correction mechanisms:  
>> 1. **Gyro (IMU)** - Corrects angular drift for straight tracking  
>> 2. **Inner Wall Distance** - Maintains consistent offset from track edge  
>> 3. **Outer Wall Avoidance** - Prevents collision when too close  
>> 4. **Vision Tracking** - Follows Limelight-detected targets when present  

> **Adaptive Speed Control**: Automatically reduces speed during sharp corrections  
> **Smart Navigation**: Behavior changes based on lap direction (`is_clockwise`) and current sensor environment  
> **Sensor Fusion**: Combines data from 3 distance sensors, 9-axis IMU, and vision system for robust decision-making

### Limelight Vision Integration:
#### Target Detection and Tracking
```python
from networktables import NetworkTables

class LimelightInterface:
    def __init__(self):
        NetworkTables.initialize(server='10.0.0.11')  # Limelight IP
        self.table = NetworkTables.getTable('limelight')
        self.set_pipeline(0)  # Default vision pipeline
    
    def get_target(self):
        """
        Retrieves current target data from Limelight
        Returns: dict with target information
        """
        tv = self.table.getNumber('tv', 0)  # Target valid (0 or 1)
        tx = self.table.getNumber('tx', 0)  # Horizontal offset (-27 to 27 degrees)
        ty = self.table.getNumber('ty', 0)  # Vertical offset (-20 to 20 degrees)
        ta = self.table.getNumber('ta', 0)  # Target area (0 to 100%)
        
        return {
            'valid': tv == 1,
            'tx': tx,
            'ty': ty,
            'area': ta,
            'distance': self.estimate_distance(ty, ta)
        }
    
    def estimate_distance(self, ty, area):
        """
        Estimates distance to target using vertical angle and area
        Calibrated through field testing
        """
        if area == 0:
            return float('inf')
        
        # Distance estimation based on target area (empirical formula)
        # Assumes known target height
        distance = (TARGET_HEIGHT * FOCAL_LENGTH) / (area ** 0.5)
        return distance
    
    def set_pipeline(self, pipeline_index):
        """Switch between vision pipelines for different detection tasks"""
        self.table.putNumber('pipeline', pipeline_index)
    
    def set_led_mode(self, mode):
        """Control Limelight LED ring (0=pipeline, 1=off, 2=blink, 3=on)"""
        self.table.putNumber('ledMode', mode)
    
    def take_snapshot(self):
        """Capture snapshot for logging/debugging"""
        self.table.putNumber('snapshot', 1)

# Usage in main code
limelight = LimelightInterface()

def vision_assisted_approach():
    """Example: Approach detected target using vision feedback"""
    while True:
        target = limelight.get_target()
        
        if not target['valid']:
            # No target - use distance sensors for navigation
            break
        
        # Center on target
        heading_correction = target['tx'] * 2.0  # Proportional gain
        servo_angle = SERVO_CENTER + int(heading_correction)
        servo.set_angle(servo_angle)
        
        # Approach until at desired distance
        if target['distance'] < APPROACH_DISTANCE:
            motor.set_speed(0)
            break
        else:
            motor.set_speed(APPROACH_SPEED)
        
        time.sleep(0.05)
```
> **NetworkTables Communication**: Standard FRC protocol for reliable Limelight data exchange  
> **Real-time Targeting**: Provides horizontal/vertical offsets for precision alignment  
> **Distance Estimation**: Calculates range to target using area and angle measurements  
> **Pipeline Switching**: Can toggle between different vision configurations (colors, AprilTags, neural networks)  
> **Competition Application**: Used for detecting colored markers, game elements, or positioning targets

---

## 🎯 Competition Challenges

<table>
  <tr>
    <td width="49%" align="center">
      <h3>🔗 Open Challenge</h3>
      <a href="https://www.youtube.com/watch?v=JMByIIizngU">
        
      </a>
      <p><a href="https://www.youtube.com/watch?v=JMByIIizngU">Watch Open Challenge Round</a></p>
      <p><em>Autonomous navigation using IMU and distance sensors for lap completion and precision parking</em></p>
    </td>
    <td width="49%" align="center">
      <h3>🔗 Obstacle Challenge</h3>
      <a href="https://www.youtube.com/watch?v=UUE0Nfv7lps">
        
      </a>
      <p><a href="https://www.youtube.com/watch?v=UUE0Nfv7lps">Watch Obstacle Challenge Round</a></p>
      <p><em>Vision-based obstacle detection and avoidance with dynamic path planning</em></p>
    </td>
  </tr>
</table>

### Challenge Descriptions:

#### Open Challenge
The Open Challenge tests fundamental autonomous navigation capabilities:
- **3 Lap Completion**: Navigate the track clockwise or counterclockwise for exactly 3 laps
- **Wall Following**: Maintain consistent distance from inner wall while avoiding outer wall
- **Corner Detection**: Accurately detect and count all 12 corners using side distance sensors
- **Precision Parking**: Enter designated parking zone and stop within boundaries
- **Time Optimization**: Complete course as quickly as possible while maintaining accuracy

Our strategy uses the REV 9-Axis IMU for maintaining straight-line trajectory between corners, REV distance sensors for wall following and corner detection, and precise turn execution using gyroscope feedback. The lap counting system tracks edges reliably across varying track widths.

#### Obstacle Challenge  
The Obstacle Challenge adds dynamic obstacle avoidance:
- **Random Obstacles**: Red and green colored blocks placed at unknown positions
- **Color Detection**: Use Limelight 3A to identify obstacle colors in real-time
- **Avoidance Logic**: Pass red blocks on right side, green blocks on left side
- **Dynamic Replanning**: Adjust trajectory mid-lap based on obstacle positions
- **Lap Completion**: Complete 3 laps while correctly navigating all obstacles
- **Parking**: Final precision parking after obstacle course completion

We employ multiple Limelight vision pipelines: one for red detection, one for green detection, and high-frequency pipeline switching to track multiple obstacles. The robot calculates avoidance paths using obstacle position data combined with distance sensor inputs for safe clearance.

---

##  Spoilers

> We initially tried using AprilTags for absolute positioning, but the detection range was too limited at competition speeds. Switched to HSV color blob detection with dynamic threshold adjustment based on ambient lighting - **much more robust**. Turns out sometimes simpler is better 🎯.

> The Raspberry Pi 5's improved GPIO performance was a game-changer. Previous Pi models struggled with precise servo timing and I²C communication simultaneously. The RP1 I/O controller eliminated that bottleneck completely, giving us **sub-millisecond response times** ⚡.

> We spent weeks optimizing PID gains, only to discover that **adaptive gain scheduling** based on robot speed made everything smoother. High gains during slow turns, lower gains at speed = butter-smooth navigation 🧈.

> Battery voltage drop during motor acceleration was causing servo jitter. Solution? Separate BEC regulators for servo power and logic power. Cost: $12. **Problem solved** 🔋.

> Our first 3D printed IMU mount had the sensor slightly off-center (2cm offset). The rotational acceleration noise was making the gyro data unusable. Moved it to exact center of rotation = **perfect data**. Lesson learned: precision matters 📐.

> The Limelight's Edge TPU can run neural networks, but **color blob detection at 90fps is faster and more reliable** for our application. We keep the neural network pipeline as backup for complex scenes. Sometimes you don't need the fanciest tool 🎨.

> Pro tip: Use **heat-set inserts** in 3D printed parts instead of threading directly into plastic. We broke three mounts before learning this. Now everything is indestructible 💪.

---

##  Contact & Links

- **GitHub Repository**: [WRO-FUTURE-ENGINEERS-2025](https://github.com/oracleapolloo/WRO-FUTURE-ENGINEERS-2025)
- **Team Email**: contact.teamapollo@gmail.com
- **Competition**: World Robot Olympiad 2025 - Future Engineers Category

---

##  Acknowledgments

Special thanks to:
- Our mentors and coaches for guidance throughout development
- REV Robotics for excellent documentation and support
- The WRO community for sharing knowledge and strategies
- Our families for supporting late-night testing sessions

---

##  License

This project is documented for educational purposes as part of the WRO 2025 competition. All custom code and designs are shared under MIT License for the benefit of the robotics community.

---

**Built with dedication by Team Apollo 🚀**

*Making autonomous vehicles smarter, one competition at a time.*

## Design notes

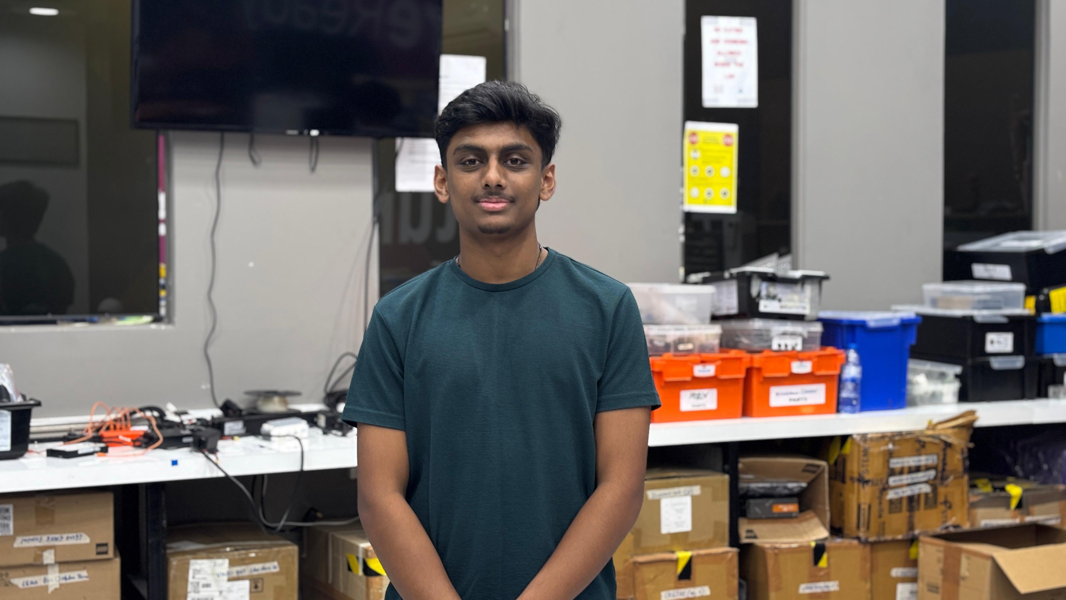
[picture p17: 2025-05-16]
t-photos/pranav pic wro.jpg

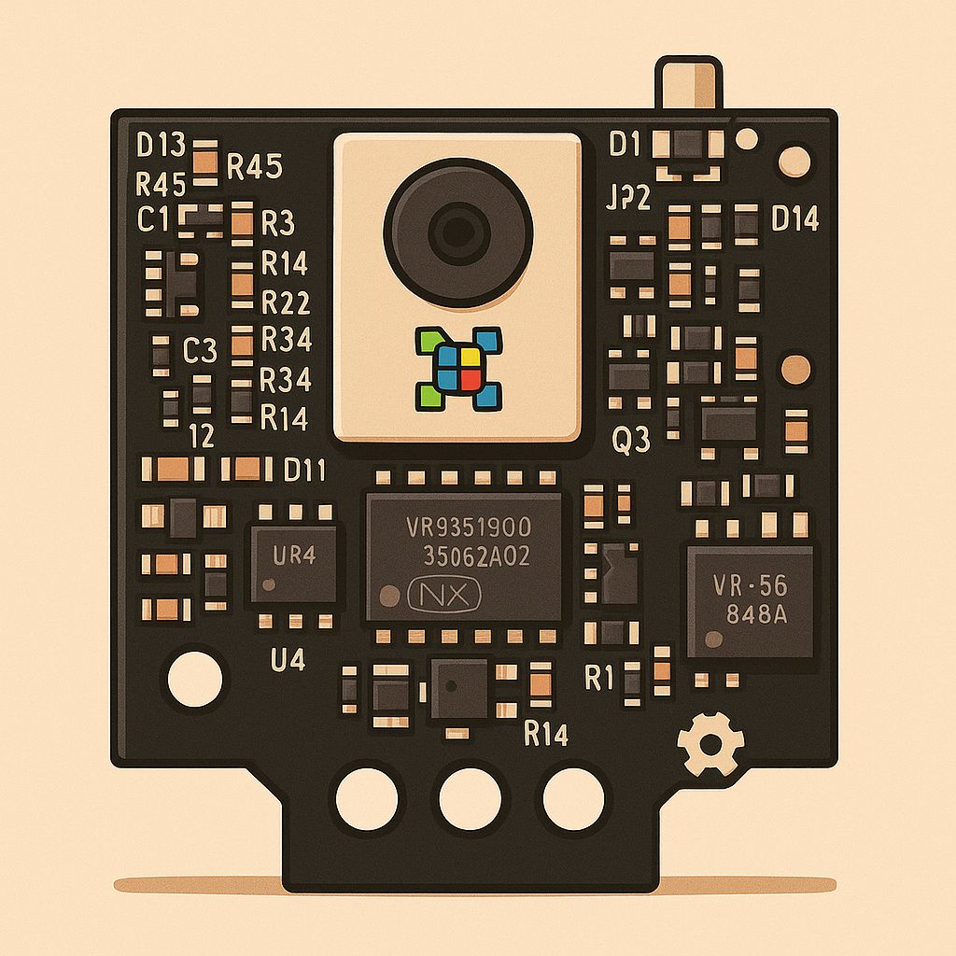
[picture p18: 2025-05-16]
other/PixyCam.JPG

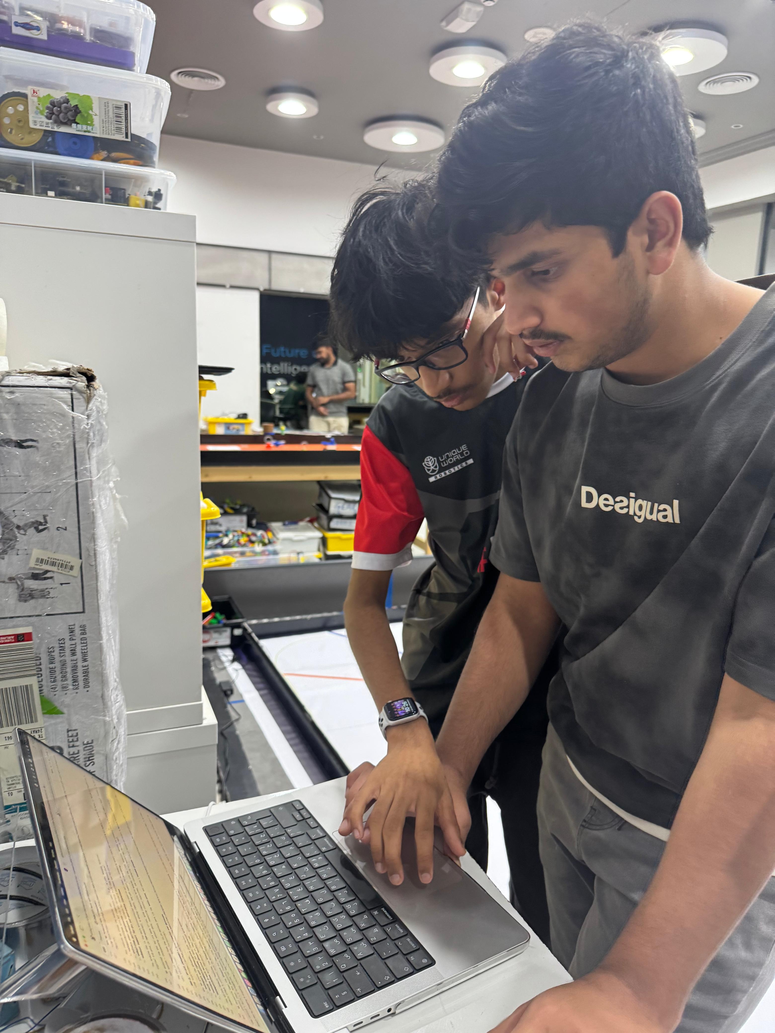
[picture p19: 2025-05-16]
t-photos/wro pic 4.jpg

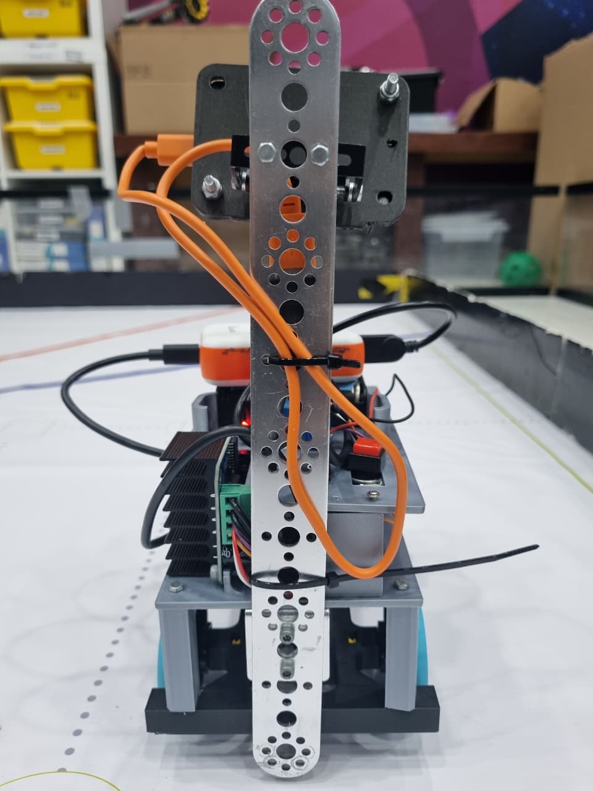
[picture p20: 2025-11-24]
v-photos/back.jpeg

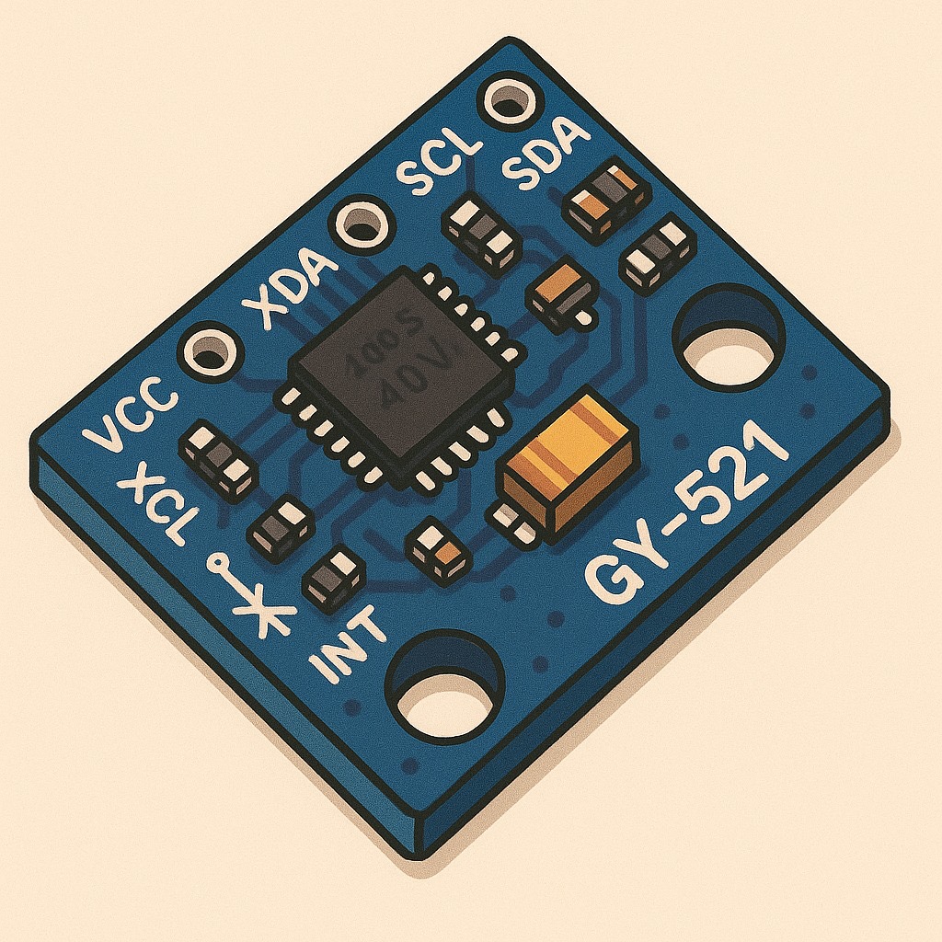
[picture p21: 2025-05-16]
other/GY-521.JPG

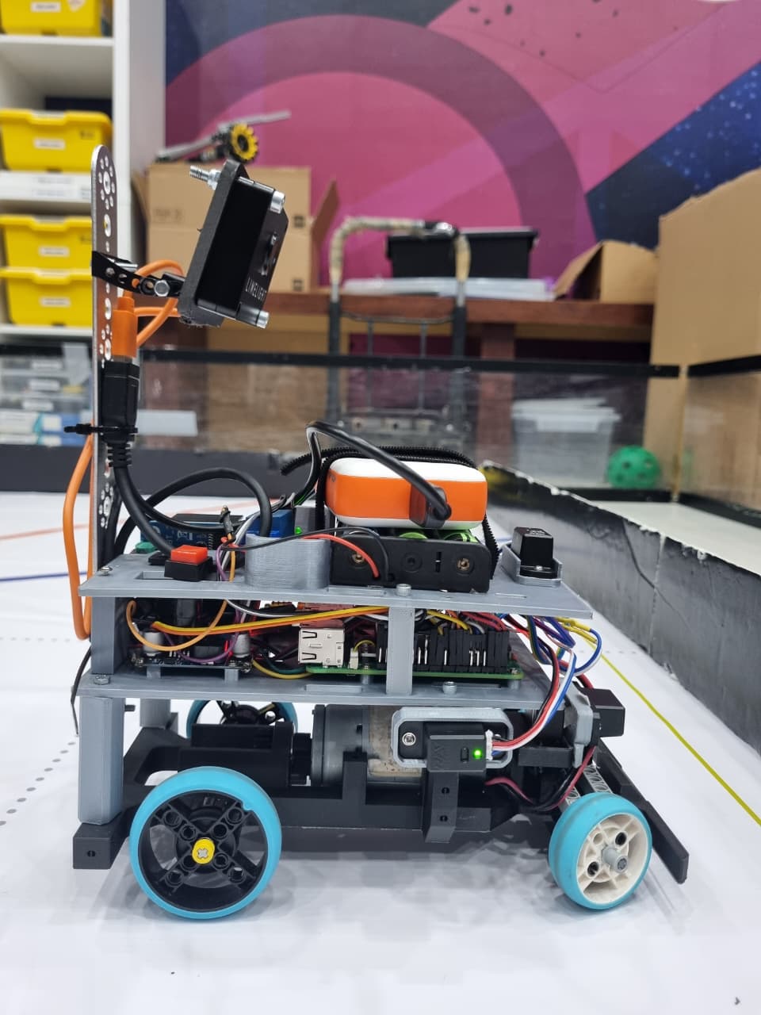
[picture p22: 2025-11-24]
v-photos/right.jpeg

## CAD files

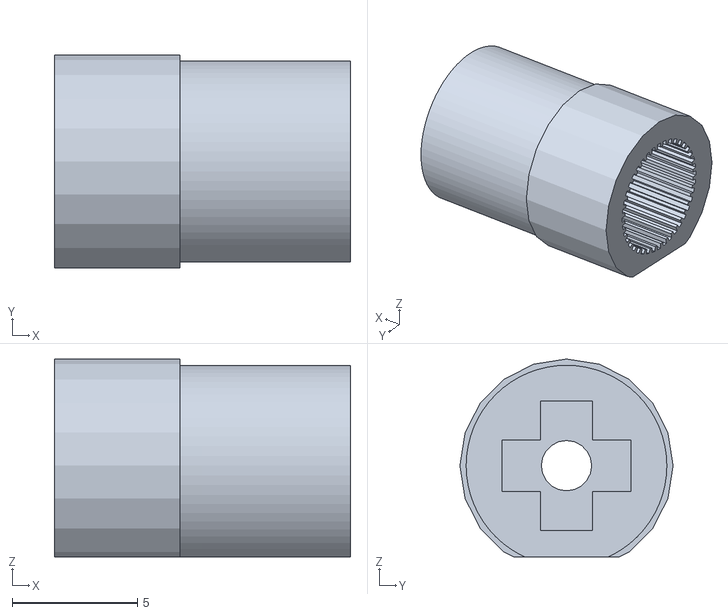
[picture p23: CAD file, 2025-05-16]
model/adapter.stl
11.8 x 8.50 x 7.89

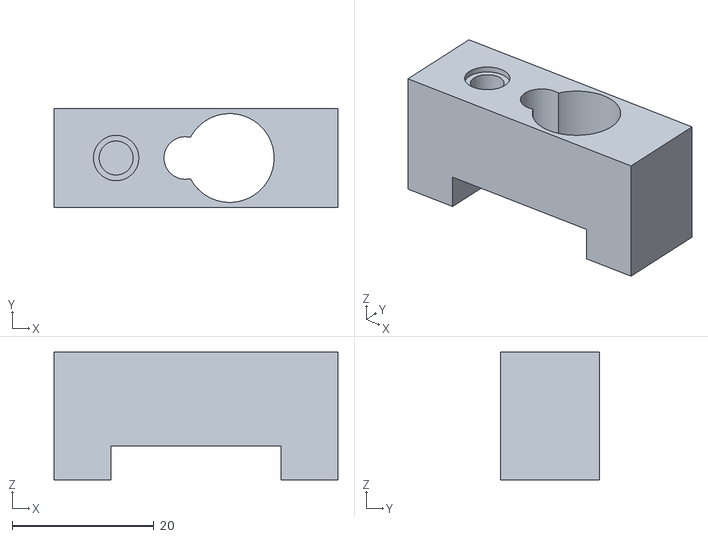
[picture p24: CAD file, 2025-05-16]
model/Servobracket.stl
40.0 x 14.0 x 18.0

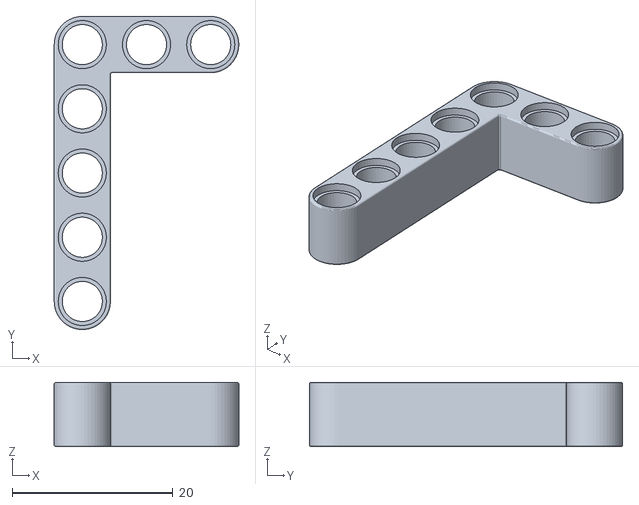
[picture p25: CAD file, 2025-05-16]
model/beam.stl
23.0 x 39.0 x 8.00

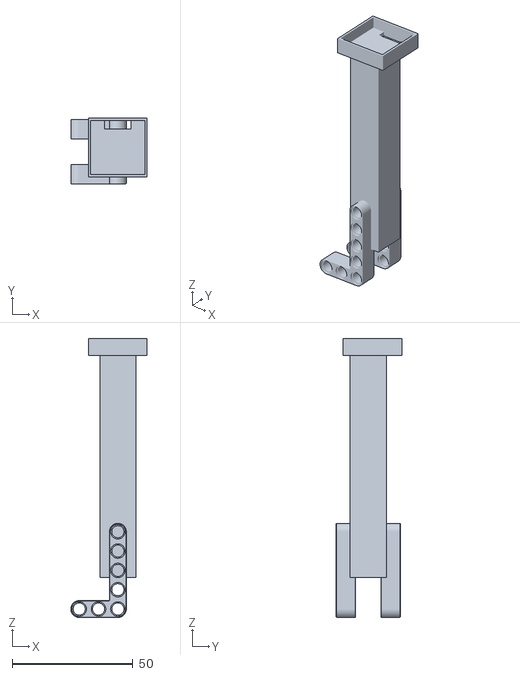
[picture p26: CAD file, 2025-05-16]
model/gyrostand.stl
31.6 x 27.1 x 115.5

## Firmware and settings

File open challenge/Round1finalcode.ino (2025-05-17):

#include <Wire.h>
#include <MPU6050_light.h>
#include <Servo.h>
#include <NewPing.h>

// Pin definitions
#define TRIG_PIN_LEFT A3     // Left ultrasonic trigger
#define ECHO_PIN_LEFT A2     // Left ultrasonic echo
#define TRIG_PIN_RIGHT A1    // Right ultrasonic trigger
#define ECHO_PIN_RIGHT A0    // Right ultrasonic echo
#define SERVO_PIN 7         // Servo signal
#define MOTOR_ENB 3          // L298N speed control
#define MOTOR_IN3 4          // L298N direction 1
#define MOTOR_IN4 5          // L298N direction 2
#define BUTTON_PIN 2         // Push button

// Ultrasonic setup
#define MAX_DISTANCE 500     // Max distance (cm)
NewPing sonarLeft(TRIG_PIN_LEFT, ECHO_PIN_LEFT, MAX_DISTANCE);
NewPing sonarRight(TRIG_PIN_RIGHT, ECHO_PIN_RIGHT, MAX_DISTANCE);

// MPU6050 and Servo
MPU6050 mpu(Wire);
Servo steeringServo;

// Constants
const int MOTOR_SPEED = 180;  // PWM speed
const int SLOW_SPEED = 120;  // Reduced speed for turns
const float SIDE_TURN_DISTANCE = 100; // Side sensor trigger (cm)
const int TOTAL_EDGES = 12;   // 4 corners * 3 laps
const int SERVO_CENTER = 90;  // Servo center
const int SERVO_MAX_LEFT = 150; // Max left
const int SERVO_MAX_RIGHT = 40; // Max right
const float KP = 2.0;         // Gyro correction gain
const float KW = 2.0;         // Inner wall-following gain
const float KO = 1.0;         // Outer wall avoidance gain (increased)
const float TARGET_WALL_DISTANCE = 30; // Target inner wall distance (cm)
const float OUTER_WALL_THRESHOLD = 30; // Outer wall crash threshold (cm) (increased)
const unsigned long WAIT_DURATION = 1500; // 1s wait post-turn

// Variables
bool isClockwise = false;
bool directionSet = false;
int edgeCount = 0;
bool isRunning = false;
float targetAngle = 0;
bool lastButtonState = HIGH;
bool isWaiting = false;
unsigned long waitStartTime = 0;

float getFilteredDistance(NewPing &sonar) {
  const int samples = 5; // Increased for better reliability
  float sum = 0;
  for (int i = 0; i < samples; i++) {
    float dist = sonar.ping_cm();
    if (dist == 0) dist = MAX_DISTANCE;
    sum += dist;
    delay(10);
  }
  return sum / samples;
}

void resetState() {
  isClockwise = false;
  directionSet = false;
  edgeCount = 0;
  targetAngle = 0;
  isWaiting = false;
  steeringServo.write(SERVO_CENTER); // Servo to 90°
  digitalWrite(MOTOR_IN3, HIGH);
  digitalWrite(MOTOR_IN4, LOW);
  analogWrite(MOTOR_ENB, 0); // Motor off
  mpu.calcOffsets(); // Recalibrate MPU6050
  Serial.println("State reset: Servo at 90°, motor off, MPU6050 recalibrated.");
}

void performTurn(bool clockwise) {
  mpu.update();
  float startAngle = mpu.getAngleZ();
  float turnTarget = startAngle + (clockwise ? -85 : 85);
  Serial.print("Initiating 90-degree turn: Target=");
  Serial.println(turnTarget);

  analogWrite(MOTOR_ENB, 0);
  steeringServo.write(clockwise ? SERVO_MAX_RIGHT : SERVO_MAX_LEFT);
  while (abs(mpu.getAngleZ() - turnTarget) > 2) {
    mpu.update();
    analogWrite(MOTOR_ENB, SLOW_SPEED);
  }
  analogWrite(MOTOR_ENB, 0);
  steeringServo.write(SERVO_CENTER);
  targetAngle = turnTarget;
  Serial.println("Turn complete: Servo reset to center.");
}

void setup() {
  Serial.begin(9600);
  Wire.begin();
  if (mpu.begin() != 0) {
    Serial.println("MPU6050 failed!");
    while (1);
  }
  // INITIAL RESET: Set servo to 90°, motor off, configure pins
  mpu.calcOffsets(); // Calibrate MPU6050
  pinMode(MOTOR_ENB, OUTPUT);
  pinMode(MOTOR_IN3, OUTPUT);
  pinMode(MOTOR_IN4, OUTPUT);
  pinMode(BUTTON_PIN, INPUT_PULLUP);
  steeringServo.attach(SERVO_PIN);
  steeringServo.write(SERVO_CENTER); // Servo to 90°
  digitalWrite(MOTOR_IN3, HIGH);
  digitalWrite(MOTOR_IN4, LOW);
  analogWrite(MOTOR_ENB, 0); // Motor off
  Serial.println("Setup complete: Servo at 90°, motor off, ready for button press.");
}

void loop() {
  bool currentButtonState = digitalRead(BUTTON_PIN);
  if (currentButtonState == LOW && lastButtonState == HIGH) {
    if (!isRunning) {
      Serial.println("Button pressed: Starting navigation...");
      resetState(); // Reset for fresh start
      isRunning = true;
    } else {
      Serial.println("Button pressed: Stopping and resetting...");
      resetState(); // Full reset to fresh state
      isRunning = false;
    }
    delay(200); // Debounce
  }
  lastButtonState = currentButtonState;

  if (!isRunning) return;

  mpu.update();
  float currentAngle = mpu.getAngleZ();
  float leftDist = getFilteredDistance(sonarLeft);
  float rightDist = getFilteredDistance(sonarRight);

  // Gyro, inner wall, and outer wall correction
  float gyroError = targetAngle - currentAngle;
  int servoAngle = SERVO_CENTER;
  float outerError = 0; // Initialize for debugging
  if (directionSet && !isWaiting) {
    float innerDist = isClockwise ? leftDist : rightDist; // Inner wall
    float outerDist = isClockwise ? rightDist : leftDist; // Outer wall
    float wallError = TARGET_WALL_DISTANCE - innerDist;  // Inner wall error (~30 cm)
    outerError = outerDist < OUTER_WALL_THRESHOLD ? OUTER_WALL_THRESHOLD - outerDist : 0; // Outer wall error (<30 cm)
    // DRIFTING LOGIC: Adjusts servo to drift toward/away from inner wall (~30 cm) and inward if outer wall <30 cm
    servoAngle += (int)(KP * gyroError + KW * wallError + KO * outerError);
  } else {
    servoAngle += (int)(KP * gyroError);
  }
  servoAngle = constrain(servoAngle, SERVO_MAX_RIGHT, SERVO_MAX_LEFT);
  steeringServo.write(servoAngle);

  int currentSpeed = MOTOR_SPEED;
  analogWrite(MOTOR_ENB, currentSpeed);

  static unsigned long lastPrint = 0;
  if (millis() - lastPrint >= 500) {
    Serial.print("Angle=");
    Serial.print(currentAngle);
    Serial.print(", Target=");
    Serial.print(targetAngle);
    Serial.print(", Servo=");
    Serial.print(servoAngle);
    Serial.print(", Speed=");
    Serial.print(currentSpeed);
    Serial.print(" | Left=");
    Serial.print(leftDist);
    Serial.print(", Right=");
    Serial.print(rightDist);
    Serial.print(", OuterError=");
    Serial.println(outerError);
    lastPrint = millis();
  }

  if (!directionSet) {
    if (rightDist > SIDE_TURN_DISTANCE && rightDist < MAX_DISTANCE) {
      isClockwise = true;
      directionSet = true;
      edgeCount++;
      Serial.print("First corner: Clockwise, Edge=");
      Serial.println(edgeCount);
      performTurn(isClockwise);
      isWaiting = true;
      waitStartTime = millis();
    } else if (leftDist > SIDE_TURN_DISTANCE && leftDist < MAX_DISTANCE) {
      isClockwise = false;
      directionSet = true;
      edgeCount++;
      Serial.print("First corner: Anticlockwise, Edge=");
      Serial.println(edgeCount);
      performTurn(isClockwise);
      isWaiting = true;
      waitStartTime = millis();
    }
  }

  if (directionSet) {
    if (isWaiting) {
      if (millis() - waitStartTime >= WAIT_DURATION) {
        isWaiting = false;
        Serial.println("Wait complete");
      } else {
        return;
      }
    }

    float outerDist = isClockwise ? rightDist : leftDist; // Outer wall for edge
    if (outerDist > SIDE_TURN_DISTANCE && outerDist < MAX_DISTANCE) {
      edgeCount++;
      Serial.print("Edge detected: Count=");
      Serial.println(edgeCount);
      if (edgeCount >= TOTAL_EDGES) {
        Serial.println("Finished 3 laps! Performing final maneuver...");
        performTurn(isClockwise); // 85-degree turn in same direction
        Serial.println("Moving forward for 750 ms...");
        steeringServo.write(SERVO_CENTER); // Straight
        analogWrite(MOTOR_ENB, MOTOR_SPEED); // Move forward
        delay(750); // 750 ms
        analogWrite(MOTOR_ENB, 0); // Stop motor
        isRunning = false;
        Serial.println("Final maneuver complete. Vehicle stopped.");
        while (1);
      }
      performTurn(isClockwise);
      isWaiting = true;
      waitStartTime = millis();
    }
  }
}

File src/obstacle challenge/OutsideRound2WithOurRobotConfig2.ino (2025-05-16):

#include <Servo.h>
#include <Pixy2.h>
#include <Wire.h>
#include <MPU6050.h>

// === Pin Configuration ===
#define SERVO_PIN 7
#define SERVO_CENTER 90
#define SERVO_MAX_LEFT 150
#define SERVO_MAX_RIGHT 40

#define TRIG_PIN_LEFT A3
#define ECHO_PIN_LEFT A2
#define TRIG_PIN_RIGHT A1
#define ECHO_PIN_RIGHT A0

#define MOTOR_ENB 3
#define MOTOR_IN3 4
#define MOTOR_IN4 5

#define BUTTON_PIN 2

// === Objects ===
Servo servo_9;
Pixy2 pixy;
MPU6050 gyro;

// === Variables ===
float leftdist = 0, rightdist = 0;
float currentAngle = 0, straightAngle = 0, offsetZ = 0;
int clockwise = 0, anticlockwise = 0;
bool green1 = false, red1 = false;
bool isRunning = false;
int turnCount = 0;
int colorX = 0, blockHeight = 0;
unsigned long previousTime = 0;
unsigned long previousButtonMillis = 0;
const unsigned long debounceInterval = 50;

// === Function Prototypes ===
long readUltrasonicDistance(int triggerPin, int echoPin);
void Forward();
void Stop();
void MeasureDistance();
void calibrateGyro();
void updateGyroAngle();
void rotate90Degrees();
void goStraight();
void findClosestBlock();
void avoidBlock();

void setup() {
  Serial.begin(9600);
  Wire.begin();
  Wire.setClock(400000);
  gyro.initialize();
  servo_9.attach(SERVO_PIN);
  pixy.init();
  pinMode(BUTTON_PIN, INPUT_PULLUP);
  pinMode(MOTOR_ENB, OUTPUT);
  pinMode(MOTOR_IN3, OUTPUT);
  pinMode(MOTOR_IN4, OUTPUT);

  if (!gyro.testConnection()) {
    Serial.println("MPU6050 connection failed.");
    while (1);
  }

  servo_9.write(SERVO_CENTER);
  calibrateGyro();
}

void loop() {
  // Button toggle with debouncing
  if (digitalRead(BUTTON_PIN) == LOW) {
    unsigned long currentMillis = millis();
    if (currentMillis - previousButtonMillis >= debounceInterval) {
      previousButtonMillis = currentMillis;
      isRunning = !isRunning;
      if (isRunning) {
        turnCount = 0;
        clockwise = 0;
        anticlockwise = 0;
        Forward();
        Serial.println("Started moving forward");
      } else {
        Stop();
        Serial.println("Stopped");
      }
    }
    while (digitalRead(BUTTON_PIN) == LOW); // Wait for release
  }

  if (isRunning && turnCount < 4) {
    MeasureDistance();

    // Initial path selection
    if (clockwise == 0 && anticlockwise == 0) {
      if (leftdist > 90) {
        anticlockwise = 1;
        Serial.println("Chose anticlockwise");
        rotate90Degrees(); // Left turn
        straightAngle = currentAngle;
      } else if (rightdist > 90) {
        clockwise = 1;
        Serial.println("Chose clockwise");
        rotate90Degrees(); // Right turn
        straightAngle = currentAngle;
      }
    } else {
      // Main navigation
      pixy.ccc.getBlocks();
      findClosestBlock();
      if (green1 || red1) {
        avoidBlock();
      } else {
        goStraight();
      }

      // Check for corner
      if (anticlockwise && leftdist > 90) {
        rotate90Degrees(); // Left turn
        straightAngle = currentAngle;
        turnCount++;
        Serial.print("Turn count: ");
        Serial.println(turnCount);
      } else if (clockwise && rightdist > 90) {
        rotate90Degrees(); // Right turn
        straightAngle = currentAngle;
        turnCount++;
        Serial.print("Turn count: ");
        Serial.println(turnCount);
      }
    }
  }

  if (turnCount >= 4 && isRunning) {
    isRunning = false;
    Stop();
    Serial.println("Completed one round, stopped");
  }
}

long readUltrasonicDistance(int triggerPin, int echoPin) {
  pinMode(triggerPin, OUTPUT);
  digitalWrite(triggerPin, LOW);
  delayMicroseconds(2);
  digitalWrite(triggerPin, HIGH);
  delayMicroseconds(10);
  digitalWrite(triggerPin, LOW);
  pinMode(echoPin, INPUT);
  return pulseIn(echoPin, HIGH);
}

void Forward() {
  analogWrite(MOTOR_ENB, 100);
  digitalWrite(MOTOR_IN3, HIGH);
  digitalWrite(MOTOR_IN4, LOW);
}

void Stop() {
  analogWrite(MOTOR_ENB, 0);
}

void MeasureDistance() {
  leftdist = 0.01723 * readUltrasonicDistance(TRIG_PIN_LEFT, ECHO_PIN_LEFT);
  delay(10);
  rightdist = 0.01723 * readUltrasonicDistance(TRIG_PIN_RIGHT, ECHO_PIN_RIGHT);
  delay(10);
}

void calibrateGyro() {
  int numReadings = 200;
  long totalZ = 0;
  for (int i = 0; i < numReadings; i++) {
    gyro.getRotationZ();
    delay(10);
  }
  for (int i = 0; i < numReadings; i++) {
    int16_t gz = gyro.getRotationZ();
    totalZ += gz;
    delay(10);
  }
  offsetZ = totalZ / (float)numReadings / 131.0;
  Serial.print("Gyroscope Z-axis offset: ");
  Serial.println(offsetZ);
}

void updateGyroAngle() {
  int16_t gz;
  unsigned long currentTime = millis();
  float deltaTime = (currentTime - previousTime) / 1000.0;
  previousTime = currentTime;
  gz = gyro.getRotationZ();
  float rotationZ = (gz / 131.0) - offsetZ;
  currentAngle += rotationZ * deltaTime;
  Serial.print("Current Angle: ");
  Serial.println(currentAngle);
}

void rotate90Degrees() {
  float targetAngle = currentAngle + (anticlockwise ? 90 : -90);
  int turnSpeed = 100; // Reduced PWM for controlled turn
  analogWrite(MOTOR_ENB, turnSpeed);
  digitalWrite(MOTOR_IN3, HIGH);
  digitalWrite(MOTOR_IN4, LOW);

  while (abs(currentAngle - targetAngle) > 2) {
    updateGyroAngle();
    if (anticlockwise) {
      servo_9.write(SERVO_MAX_LEFT);
    } else {
      servo_9.write(SERVO_MAX_RIGHT);
    }
  }

  servo_9.write(SERVO_CENTER);
  analogWrite(MOTOR_ENB, 100); // Restore normal speed
  Serial.println("Completed 90-degree turn");
}

void goStraight() {
  int deadzone = 5;
  if (currentAngle > straightAngle + deadzone) {
    servo_9.write(SERVO_CENTER - 20); // Steer left
  } else if (currentAngle < straightAngle - deadzone) {
    servo_9.write(SERVO_CENTER + 20); // Steer right
  } else {
    servo_9.write(SERVO_CENTER);
  }
  updateGyroAngle();
  Serial.print("Maintaining straight angle: ");
  Serial.println(straightAngle);
}

void findClosestBlock() {
  green1 = false;
  red1 = false;
  colorX = 0;
  blockHeight = 0;
  int j = 0;

  for (int i = 0; i < pixy.ccc.numBlocks; i++) {
    if (pixy.ccc.blocks[i].m_height > blockHeight) {
      blockHeight = pixy.ccc.blocks[i].m_height;
      j = i;
    }
  }

  if (pixy.ccc.numBlocks > 0) {
    if (pixy.ccc.blocks[j].m_signature == 1) {
      green1 = true;
      colorX = pixy.ccc.blocks[j].m_x;
      Serial.println("Green block detected");
    } else if (pixy.ccc.blocks[j].m_signature == 2) {
      red1 = true;
      colorX = pixy.ccc.blocks[j].m_x;
      Serial.println("Red block detected");
    }
  }
}
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

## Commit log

2025-05-15 added arduino uno
2025-05-15 changed the arduino place in hardware used
2025-05-16 Update 3d printer components error n add images for hardware used
2025-05-16 Update number of servo used
2025-05-16 Updated camera hardware used error
2025-05-16 Rename 3D-Printed Bot.jpg to other/3D-Printed Bot.jpg
2025-05-16 Rename Arduino UNO.jpeg to other/Arduino UNO.jpeg
2025-05-16 add model files
    [Servobracket.stl, adapter.stl, beam.stl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]
2025-10-25 Update the challenge one, fixed the bugs for ultrasonic sensors
2025-10-28 Update pixycheck.ino
    camera check changes
2025-11-08 fixed bugs n added new calibration to camera by using roboflow and also fixed motor gear box README.md
2025-11-17 Update all of the parts and list description from V1 to the current Version .md
2025-11-22 Updated distance and servo pictures README.md
